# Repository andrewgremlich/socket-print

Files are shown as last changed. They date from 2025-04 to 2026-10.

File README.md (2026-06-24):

# Socket Print (Provel Print)

A utility CAD-like application to apply modifications to a prosthetic limb socket STL file, and output the modifications to a GCode file.

## Getting Started

Requires Node.js 24+ (see `.nvmrc`).

```bash
git clone https://github.com/andrewgremlich/socket-print.git
cd socket-print
npm install
npm run dev
```

Open <http://localhost:4200>.

### Other commands

```bash
npm run build            # Production build (runs tests first)
npm run test             # Run Vitest
npm run check            # TypeScript + Biome
npm run knip             # Find unused files/exports/deps
```

## Deployment

The app is a fully static site deployed to **Cloudflare Workers** via [Workers Static Assets](https://developers.cloudflare.com/workers/static-assets/). No Worker script is required — Cloudflare serves the `dist/` build directly from the edge. Config lives in [wrangler.jsonc](wrangler.jsonc); edge caching/header rules live in [public/\_headers](public/_headers).

```bash
npm run deploy        # Build, then `wrangler deploy`
npm run cf:preview    # Build, then serve the production bundle locally via `wrangler dev`
```

### CI deploys

[.github/workflows/deploy-cloudflare.yml](.github/workflows/deploy-cloudflare.yml) deploys on every push to `main`. Set these repository secrets:

- `CLOUDFLARE_API_TOKEN` — a token with the **Edit Cloudflare Workers** permission
- `CLOUDFLARE_ACCOUNT_ID` — your Cloudflare account ID

The first deploy (locally via `npm run deploy`) creates the Worker and prints its `*.workers.dev` URL; attach a custom domain in the Cloudflare dashboard or via a `routes` entry in `wrangler.jsonc`.

## Offline Support

The app installs a service worker for offline use. See [SERVICE_WORKER.md](SERVICE_WORKER.md).

## Testing GCode Output

To inspect a generated GCode file, use [NCViewer](https://ncviewer.com/).

## Coordinate System Transformation

This application bridges two different coordinate system conventions:

- **Three.js (3D visualization)**: Y-up coordinate system where Y is the vertical axis
- **3D Printing / GCode**: Z-up coordinate system where Z is the vertical axis

### Why This Matters

When generating GCode from Three.js geometries, coordinate transformations are necessary to convert between these systems:

1. **In Three.js**: Objects are positioned with Y representing height
2. **In GCode**: The Z axis represents height (vertical movement)

### Where Transformations Occur

- **[src/3d/generateGCode.ts](src/3d/generateGCode.ts)** — `makeGCodePoint()` and `flipVerticalAxis()` handle the Y↔Z swap when emitting GCode points
- **[src/3d/sliceWorker.ts](src/3d/sliceWorker.ts)** — points are collected in Three.js (Y-up) space and later transformed during GCode generation

Variables like `verticalAxis` and `flipHeight` carry this transformation through the pipeline.

## References

- Pellet extruder flow / RPM: https://dyzedesign.com/2024/05/flow-to-rpm-factor-optimize-your-3d-printing-with-pellet-extruders/
- Clipper polygon-clipping library (under evaluation): https://github.com/junmer/clipper-lib

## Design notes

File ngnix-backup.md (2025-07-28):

Files are build and deployed to `/var/www/socket-print`

`/etc/nginx/sites-enabled/socket-print` is a link to the conf file mentioned here...

`/etc/nginx/sites-available/socket-print`

```conf
server {
    listen 80;
    server_name 209.38.172.166;

    root /var/www/socket-print;

    index index.html;

    location / {
        try_files $uri $uri/ /index.html;
    }

    location ~* \.(?:js|css|png|jpg|jpeg|gif|ico|svg|woff2?|ttf|eot)$ {
        expires 365d;
        add_header Cache-Control "public, max-age=31536000, immutable";
        access_log off;
    }
}
```

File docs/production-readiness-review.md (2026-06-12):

# Production Readiness Review

**Date:** 2026-06-12
**Version reviewed:** 1.22.8 (branch `main`, commit `b33a8a9`)
**Scope:** Full review of offline/PWA capability, slicing/G-code pipeline, error handling, security, and build/test health.

## Resolution Notes (2026-06-12, commit `1fca44b`)

| # | Status | Notes |
|---|---|---|
| 1 | Fixed | Added `<link rel="manifest">` to `index.html` and `help.html` |
| 2 | Won't fix | Chrome prompts for permission on HTTP local-network requests; no change needed |
| 3 | Fixed | `.map` files filtered from precache in `vite-sw-plugin.ts`; extra STLs removed from `vite.config.ts` (only `test_stl_file.stl` kept) |
| 4 | Won't fix | `skipWaiting` kept intentionally for less user interruption |
| 5 | Fixed | Entire DONE branch in `src/renderer.ts` wrapped in try/finally; progress bar and worker always reset on error |
| 6 | Fixed | Empty slice result now throws a user-visible error before G-code generation |
| 7 | Fixed | `store.ts` top-level `initData()` caught with alert instead of silently killing the page; `PrintObject.#showError` now calls `alert()` |
| 8 | Fixed | SW fetch handler now skips non-same-origin requests (`url.origin !== self.location.origin`) |
| 9 | Deferred | Firmware flow intentionally unfinished; comes later |

---

## Verdict

Not production-ready yet. The code quality, testing, and CI are in good shape (build, type checks, and all 305 tests pass cleanly), but there are genuine production blockers — mostly around the PWA/offline story and the HTTPS-vs-printer architecture: the PWA is currently not installable, the service worker ships ~5 MB of sourcemaps to every client, the update flow can break a running session, and there is an unresolved architectural conflict between HTTPS (required for offline) and HTTP printer communication.

## Critical

### 1. The PWA is not installable — no `<link rel="manifest">` anywhere

`public/manifest.webmanifest` exists and is even precached by the service worker, but none of the three HTML files reference it. Browsers will never see it, so there's no install prompt, no standalone mode, no home-screen icon. Add `<link rel="manifest" href="/manifest.webmanifest">` to `index.html` (and ideally `help.html`).

Related: `index.html:11-12` references `/apple-touch-icon.png` and `/mask-icon.svg`, neither of which exists in `public/` — both 404.

### 2. Printer communication will likely be blocked when the app is served over HTTPS

Offline/PWA support requires HTTPS, but `src/3d/printerApi.ts` fetches `http://<printer-ip>/rr_*`. An `http:` fetch from an `https:` page is active mixed content and is blocked by Chrome, Firefox, and Safari before the request even leaves the page — the "skip printer IPs" logic in `public/sw-template.js:85-101` never gets a chance to matter. Chrome's Private Network Access rules add a second layer of blocking for public→local requests.

This means the deployed (Vercel/HTTPS) app can render and slice but **cannot send to the printer** — the core function. Options:

- Serve the app from the printer's LAN over plain HTTP (sacrificing the service worker, which only registers on HTTPS/localhost)
- Put a TLS proxy in front of the Duet
- Package the app (Electron/Tauri) where mixed-content rules don't apply

Verify this on real hardware before anything else, because it determines the whole deployment story.

### 3. The service worker precaches all sourcemaps — ~5.3 MB wasted per client, per update

`vite-sw-plugin.ts:18` takes every bundle key, including `.map` files. The generated `dist/sw.js` confirms it: `main.js.map` (1.7 MB), `three.js.map` (3 MB), `sliceWorker.js.map`, etc. Combined with 5.4 MB of sample STLs and the cache version containing `Date.now()` (so **every** build invalidates everything), each release re-downloads ~20 MB.

Filter `.map` files out of the asset list, and consider whether all four demo STLs belong in the precache.

### 4. The update flow can break an actively running session

`public/sw-template.js` uses `skipWaiting()` + `clients.claim()` + immediate deletion of old caches on activate. When an update lands mid-session, the old page is still running, but its hashed lazy assets (the `Settings` chunk, the slice worker module, fonts) are deleted from cache. If the user is offline or the server has dropped the old hashes, lazy loads fail until reload. The update banner mitigates this, but it auto-dismisses after 30 seconds (`src/web-components/UpdateNotification.ts:40-45`).

Either drop `skipWaiting` so the new SW activates on next navigation, or reload automatically on `controllerchange`, and make the banner persistent.

## High

### 5. Slicing errors leave the UI stuck

In `src/renderer.ts:204-253`, only G-code *delivery* is wrapped in try/catch. If `blendHardEdges`, `calculateFeedratePerLevel`, or `generateGCode` throws inside the async `onmessage` handler, the progress bar stays up forever, the worker is never terminated, and the user gets nothing — the try/catch around `slicingAction()` at the button level can't catch errors from that callback. Wrap the whole DONE branch and `reset()`/`terminate()` in a `finally`.

### 6. An empty slice result still produces and sends G-code

`vaseMode` in `src/3d/sliceWorker.ts:107-109` bails out of a layer (or returns `[]` entirely) when ray casts miss. The main thread doesn't check for an empty/short result — it will happily generate a header + transition layer + end sequence and upload it to the printer. For a device that extrudes hot plastic onto a prosthetic cup, guard `data.length === 0` (and arguably a minimum layer count) with a user-facing error.

### 7. No user-visible error surface for initialization/database failures

`src/db/store.ts:70` does a top-level `await initData()`; if IndexedDB is unavailable (Firefox private browsing, storage pressure, corrupted DB), the module rejection kills the entire `renderer.ts` import chain and the user gets a dead page with the loading spinner state. Similarly, `PrintObject.#showError` (`src/classes/PrintObject.ts:147-149`) only writes to `console.error`, so "Failed to save file to database" and friends are invisible. The log interceptor is a nice foundation — pair it with a simple visible error banner.

### 8. Cross-origin responses are cached forever by the cache-first strategy

The service worker fetch handler caches *any* successful GET — including `https://api.github.com/.../releases/latest` used by the firmware-update check. Cache-first means the "latest firmware" answer is frozen at whatever was first cached until the next app release rotates the cache. Limit SW caching to `location.origin`, or use network-first for non-origin requests.

### 9. The firmware flow looks unfinished

`public/firmware/release.json` contains placeholder data (`"test"`, version `0.0.0`, empty URL). If the Settings firmware-update path reads this in production, it should be populated or the feature gated before release. Also note `getLatestFirmwareRelease` is unauthenticated GitHub API (60 req/hr/IP rate limit) and online-only.

## Medium

- **Offline gaps in precache**: the Inter fonts (`/Inter/*.ttf`, referenced from `src/global-style.css`) and `/styles/update-notification.css` (loaded inside the UpdateNotification shadow DOM) aren't in the `staticAssets` list. They get runtime-cached only after first use, and a cache-version bump evicts them — a user who updates online and then goes offline loses fonts and banner styling.
- **Duplicate element**: `index.html` has `<app-info>` twice (lines 151 and 155). If its shadow-DOM-external behavior involves IDs or singleton assumptions, this is a latent bug; at minimum it's dead weight.
- **Printer reconnect gives up permanently**: after 10 failed retries (`src/utils/handlePrinterConnection.ts:65-77`), polling stops until the user edits the IP field. Consider resuming on `window` `online` events or a slow background interval, since "printer powered on after the app" is a normal sequence in a clinic.
- **No security headers**: `vercel.json` only sets `installCommand`. Adding `Content-Security-Policy`, `X-Content-Type-Options: nosniff`, and an explicit `Cache-Control: no-cache` on `/sw.js` would harden the deployment cheaply.
- **`navigator.onLine` is unreliable** as the sole signal for the OfflineIndicator (it reports "online" when connected to a router with no internet — exactly the clinic LAN scenario). A periodic fetch probe of a tiny same-origin resource is more truthful.

## Low / nits

- `index.html:8` — `<meta description="...">` is invalid; should be `<meta name="description" content="...">`.
- `manifest.webmanifest` — `short_name: "PP"` is what appears under the installed icon; icons lack `"purpose": "maskable"`; no `id` field.
- `help.html` SW comment says "both HTTPS and localhost" but the code registers only on HTTPS.
- Dead `sync`/`push` listeners in `public/sw-template.js:169-178`.
- `hotkeys("ctrl+shift+r")` re-implements a native browser shortcut — unnecessary and can mask hard-refresh.
- `src/utils/logInterceptor.ts` log array grows unbounded for the session; cap it (e.g., ring buffer of 5k entries).
- `generateGCodeButton` is cast to `HTMLInputElement` but is a `<button>` — harmless but misleading.

## What's already in good shape

- Tests: 305 passing across 23 files, with real coverage of geometry and G-code math
- Clean `tsc` + Biome checks
- Fast, reproducible production build
- Tag-vs-version validation in the release workflow
- BVH-accelerated slicing offloaded to a Web Worker
- Consistent geometry/material disposal
- IndexedDB persistence with a versioned schema and a documented migration
- Genuine accessibility effort (aria attributes, reduced-motion handling, focus management)

## Suggested priority order

1. Fix the manifest link (#1 — five minutes)
2. Strip sourcemaps from the precache (#3 — one line in `vite-sw-plugin.ts`)
3. Resolve the HTTPS/printer question (#2) on real hardware — its answer may change how much the rest of the PWA work matters

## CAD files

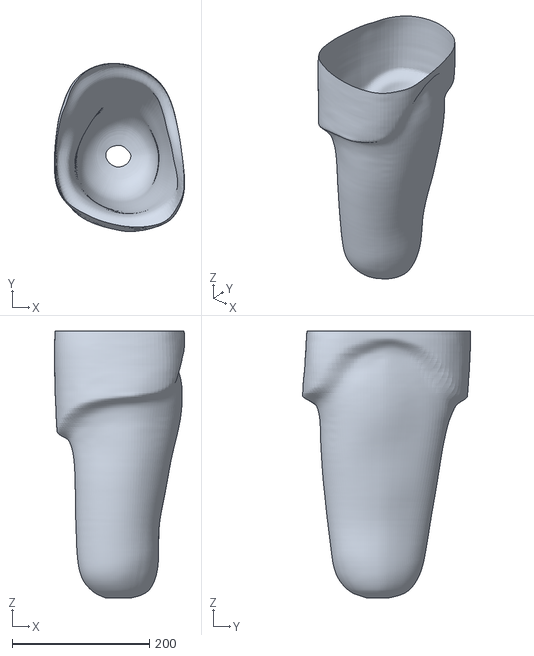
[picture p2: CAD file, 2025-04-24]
public/TF-IschialContainment.stl
189.9 x 245.2 x 389.1

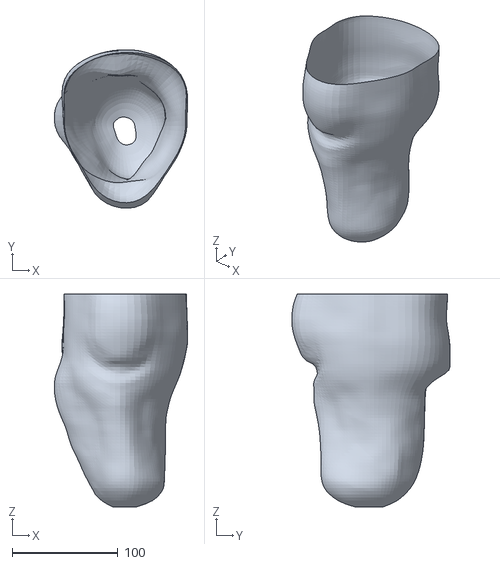
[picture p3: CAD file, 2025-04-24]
public/test_stl_file.stl
126.0 x 149.5 x 201.0

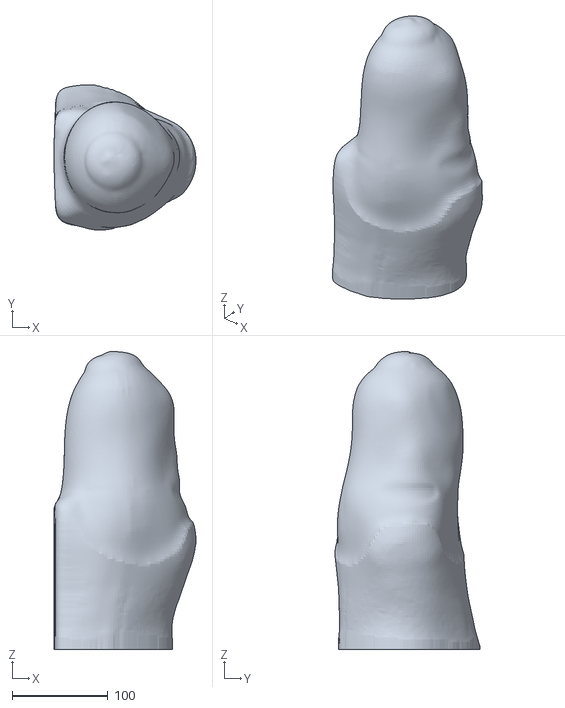
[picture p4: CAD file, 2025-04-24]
public/Crosswalk.stl
148.0 x 151.5 x 310.8

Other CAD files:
public/acme_J_needs-trimming.stl

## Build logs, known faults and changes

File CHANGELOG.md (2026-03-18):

## [1.20.2](https://github.com/andrewgremlich/socket-print/compare/v1.18.5...v1.20.2) (2026-03-18)

## [1.20.1](https://github.com/andrewgremlich/socket-print/compare/v1.19.1...v1.20.1) (2026-03-08)

## [1.20.0](https://github.com/andrewgremlich/socket-print/compare/v1.17.1...v1.20.0) (2026-03-04)

### Bug Fixes

* exclude TransformControls helper meshes from slicing geometry ([393f6a7](https://github.com/andrewgremlich/socket-print/commit/393f6a7321aeef389e59ff8a8db9675709bbcd4f))

## [1.17.1](https://github.com/andrewgremlich/socket-print/compare/v1.17.0...v1.17.1) (2026-01-29)

## [1.17.0](https://github.com/andrewgremlich/socket-print/compare/v1.16.1...v1.17.0) (2026-01-27)

### Bug Fixes

* upgrade dexie from 4.2.1 to 4.3.0 ([#17](https://github.com/andrewgremlich/socket-print/issues/17)) ([31c658d](https://github.com/andrewgremlich/socket-print/commit/31c658def43a1cc310776123de3af92c874988e5))

## [1.16.1](https://github.com/andrewgremlich/socket-print/compare/v1.16.0...v1.16.1) (2026-01-21)

## [1.16.0](https://github.com/andrewgremlich/socket-print/compare/v1.15.7...v1.16.0) (2026-01-20)

## [1.15.7](https://github.com/andrewgremlich/socket-print/compare/v1.15.6...v1.15.7) (2026-01-17)

## [1.15.6](https://github.com/andrewgremlich/socket-print/compare/v1.15.5...v1.15.6) (2026-01-15)

## [1.15.5](https://github.com/andrewgremlich/socket-print/compare/v1.15.4...v1.15.5) (2026-01-14)

## [1.15.4](https://github.com/andrewgremlich/socket-print/compare/v1.15.3...v1.15.4) (2026-01-13)

## [1.15.3](https://github.com/andrewgremlich/socket-print/compare/v1.15.2...v1.15.3) (2026-01-13)

## [1.15.2](https://github.com/andrewgremlich/socket-print/compare/v1.15.1...v1.15.2) (2026-01-13)

## [1.15.1](https://github.com/andrewgremlich/socket-print/compare/v1.14.3...v1.15.1) (2026-01-13)

## [1.14.3](https://github.com/andrewgremlich/socket-print/compare/v1.14.2...v1.14.3) (2026-01-08)

## [1.14.2](https://github.com/andrewgremlich/socket-print/compare/v1.14.1...v1.14.2) (2026-01-07)

## [1.14.1](https://github.com/andrewgremlich/socket-print/compare/v1.14.0...v1.14.1) (2026-01-07)

## [1.14.0](https://github.com/andrewgremlich/socket-print/compare/v1.13.8...v1.14.0) (2026-01-02)

## [1.13.8](https://github.com/andrewgremlich/socket-print/compare/v1.13.7...v1.13.8) (2025-12-30)

## [1.13.7](https://github.com/andrewgremlich/socket-print/compare/v1.13.6...v1.13.7) (2025-12-26)

## [1.13.6](https://github.com/andrewgremlich/socket-print/compare/v1.13.5...v1.13.6) (2025-12-26)

## [1.13.5](https://github.com/andrewgremlich/socket-print/compare/v1.13.4...v1.13.5) (2025-12-24)

## [1.13.4](https://github.com/andrewgremlich/socket-print/compare/v1.13.3...v1.13.4) (2025-12-24)

## [1.13.3](https://github.com/andrewgremlich/socket-print/compare/v1.13.2...v1.13.3) (2025-12-24)

## [1.13.2](https://github.com/andrewgremlich/socket-print/compare/v1.13.1...v1.13.2) (2025-11-04)

## [1.13.1](https://github.com/andrewgremlich/socket-print/compare/v1.13.0...v1.13.1) (2025-11-04)

## [1.13.0](https://github.com/andrewgremlich/socket-print/compare/v1.12.5...v1.13.0) (2025-10-31)

## [1.12.5](https://github.com/andrewgremlich/socket-print/compare/v1.12.4...v1.12.5) (2025-10-27)

## [1.12.4](https://github.com/andrewgremlich/socket-print/compare/v1.12.3...v1.12.4) (2025-10-23)

## [1.12.3](https://github.com/andrewgremlich/socket-print/compare/v1.12.2...v1.12.3) (2025-10-23)

### Bug Fixes

* nozzle temp not setting for machine ([908c6d9](https://github.com/andrewgremlich/socket-print/commit/908c6d91b1a3ad1b6987bafc9848d77e6ec3962f))

## [1.12.2](https://github.com/andrewgremlich/socket-print/compare/v1.12.1...v1.12.2) (2025-10-18)

## [1.12.1](https://github.com/andrewgremlich/socket-print/compare/v1.12.0...v1.12.1) (2025-10-18)

## [1.12.0](https://github.com/andrewgremlich/socket-print/compare/v1.11.5...v1.12.0) (2025-10-18)

## [1.11.5](https://github.com/andrewgremlich/socket-print/compare/v1.11.3...v1.11.5) (2025-10-14)

## [1.11.3](https://github.com/andrewgremlich/socket-print/compare/v1.11.1...v1.11.3) (2025-10-13)

## [1.11.1](https://github.com/andrewgremlich/socket-print/compare/v1.11.0...v1.11.1) (2025-10-09)

## [1.11.0](https://github.com/andrewgremlich/socket-print/compare/v1.10.7...v1.11.0) (2025-10-04)

## 1.10.7 (2025-10-03)

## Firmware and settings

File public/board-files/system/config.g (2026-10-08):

; Configuration file for Duet 3 MB 6XD (firmware version 3.6)
; executed by the firmware on start-up
;
; ------------------------------
; PROVEL PRINTER CONFIG FILE
; VERSION: 0.5
; DATE:2025-Feb-12
;-------------------------------
;

; General preferences
M575 P1 S1 B57600                                 ; enable support for PanelDue
G90                                               ; send absolute coordinates...
M83                                               ; ...but relative extruder moves
M550 P"ProvelPrinter1"                            ; set printer name
M586 C"*"         ;enable CORS

; Network
M552 P192.168.10.14 S1                            ; enable network and set IP address
;M553 P255.255.255.0                               ; set netmask
;M554 P192.168.10.254                               ; set gateway
M586 P0 S1                                        ; enable HTTP
M586 P1 S0                                        ; disable FTP
M586 P2 S0                                        ; disable Telnet

;pre declare speed override variable
if !exists(global.extruderFeed)
  global extruderFeed = 8200                     

; Drives
M569 P0.0 S0                                     ; physical drive 0.0 goes forwards
M569 P0.1 S0                                     ; physical drive 0.1 goes forwards
M569 P0.2 S1                                     ; physical drive 0.2 goes forwards
M569 P0.3 S0                                     ; physical drive 0.3 goes forwards
M569 P0.0 T1:1:1:1                               ;test - step pulse timing of 1uS
M569 P0.1 T1:1:1:1
M584 X0.0 Y0.1 Z0.2 E0.3                         ; set drive mapping
;M92 X14.80 Y22.2 Z210.50 E22.4                   ; set steps per mm  (if E1600 a movement of 1"mm" = 1 screw revolution)
;M92 X14.80 Y22.2 Z210.50 E51.00                  ; set steps per mm old extruder befoe gearing changes
M92 X14.80 Y22.2 Z210.50 E99.00                  ; set steps per mm  update to 51* new gear ratio

M566 X900.00 Y900.00 Z60.00 E1000.00               ; set maximum instantaneous speed changes (mm/min) extuder jer increased to allow for smooth movement with the algorithim expanded files
M203 X6000.00 Y6000.00 Z1800.00 E{global.extruderFeed} I0.001          ; set maximum speeds (mm/min) minimum feedrate
M201 X500.00 Y500.00 Z20.00 E250.00               ; set accelerations (mm/s^2)

; Axis Limits
M208 X-200:185 Y-170:250 Z0:506.6

; Endstops
M574 X1 S1 P"io3.in"                              ; configure switch-type (e.g. microswitch) endstop for low end on X via pin io3.in
M574 Y1 S1 P"io4.in"                              ; configure switch-type (e.g. microswitch) endstop for low end on Y via pin io4.in
M574 Z2 S1 P"io5.in"                              ; configure switch-type (e.g. microswitch) endstop for High end on Z via pin io5.in

; Z-Probe
M558 P0 H5 F120 T6000                             ; disable Z probe but set dive height, probe speed and travel speed
M557 X20:480 Y20:480 S40                          ; define mesh grid

; Heaters and temperature sensors
M308 S0 P"temp0" Y"thermistor" A"BedTemp" T100000 B4138              ; configure sensor 0 as thermistor on pin temp0
M950 H0 C"out2" T0                                                   ; create bed heater output on out7 and map it to sensor 0
M307 H0 R0.632 K0.373:0.000 D3.55 E1.35 S1.00 B0                     ; disable bang-bang mode for the bed heater and set PWM limit
M140 P0 H0                                                           ; map heated bed to heater 0
M143 H0 S120                                                         ; set temperature limit for heater 0 to 120C
M308 S1 P"temp1" Y"pt1000" A"NozzleTemp"                             ; configure sensor 1 as PT1000 on pin temp1
M950 H1 C"out0" T1                                                   ; create nozzle heater output on out0 and map it to sensor 1
;M307 H1 R0.836 K0.060:0.000 D43.70 E1.35 S1.00 B0 V24.1              ; old tuning for old heater barrel
;M307 H1 R1.278 K0.106:0.154 D19.00 E1.35 S1.00 B0 V24.0   
;M307 H1 R0.735 K0.046:0.000 D58.84 E1.35 S1.00 B0 V23.9              ; new barrel heater 10.04.25 
M307 H1 R0.635 K0.050:0.000 D68.50 E1.35 S1.00 B0 V24.2               ;2.19.26
M143 H1 S350                                                         ; set temperature limit for heater 1 to 350C
M570 H1 T30 P30; for development only

M308 S2 P"temp2" Y"thermistor" A"CupTemp" T100000 B4138              ; configure sensor 2 as thermistor on pin temp2
M950 H2 C"out1" T2                                                   ; create nozzle heater output on out1 and map it to sensor 2
;M307 H2 R0.796 K0.247:0.000 D12.13 E1.35 S1.00 B0                      ; disable bang-bang mode for heater  and set PWM limit
;M307 H2 R3.183 K1.538:0.000 D1.02 E1.35 S1.00 B0                    ;old tuning for old cup heater 6.18.25

;M307 H2 R1.095 K0.484:0.000 D5.98 E1.35 S1.00 B0                    ;new cup heater tuning 6.19.25 #1
;M307 H2 R1.199 K0.559:0.000 D6.43 E1.35 S1.00 B0                    ;new cup heater tuning 6.19.25 #2 extra silicon insulation
;M307 H2 R1.527 K0.635:0.000 D5.67 E1.35 S1.00 B0                    ;new cup heater tuning 6.19.25 #3 fiber insulation
;M307 H2 R1.520 K0.660:0.000 D6.01 E1.35 S1.00 B0                    ;new cup heater tuning 7.16.25 #4 sand dollar top
;M307 H2 R1.927 K0.644:0.000 D3.50 E1.35 S1.00 B0                    ;new cup heater tuning 7.23.25 #5 new heater
;M307 H2 R1.948 K0.613:0.000 D3.66 E1.35 S1.00 B0                    ;new cup heater tuning 7.25.25 #6 target 170C 
M307 H2 R1.940 K0.656:0.000 D3.53 E1.35 S1.00 B0                     ;new cup heater tuning 7.31.25 #7 target 160C

M140 P1 H2                                                           ; map cup heater as second heated bed to heater2
M143 H2 S210                                                         ; set temperature limit for heater 2 to 210C
M308 S3 P"temp3" Y"thermistor" A"EnclosureTemp" T100000 B4138        ; configure sensor 3 as thermistor on pin temp3

M950 H3 T3 C"io2.out"                     ; create a dummy heater on io2.out to allow enclosure temperature faults to be raised
M141 P0 H3                                ; configure the dummy heater as a chamber heater
M143 H3 P0 T3 A0 C0 S50                   ; configure a heater fault to be raised if the enclosure temperature goes above 50C, use heater-fault.g to handle it

M302 P0 S180 R180                         ; set temp at which cold extrude is allowed  

; Fans
M950 F0 C"!out3" Q500                              ; create fan 0 on pin out4 and set its frequency
M106 P0 C"Exhaust" S0 H-1                         ; set fan 0 name and value. Thermostatic control is turned off
M950 F1 C"!out4" Q500                              ; create fan 1 on pin out5 and set its frequency
M106 P1 C"PelletFeed" S0 H-1                            ; set fan 1 name and value. Thermostatic control is turned off
M950 F2 C"!out5" Q500                              ; create fan 2 on pin out6 and set its frequency
M106 P2 C"PartCooling" S0 H-1                            ; set fan 2 name and value. Thermostatic control is turned off
M950 F3 C"out6" Q500                              ; create fan 3 on pin out7 and set its frequency
M106 P3 C"Extruderservo" S1 H1 T100                         ; set fan 3 name and value. Thermostatic control is turned off
M950 F4 C"out7" Q500                              ; create fan 3 on pin out7 and set its frequency
M106 P4 C"PelletPump" S0 H-1                          ; set fan 3 name and value. Thermostatic control is turned off

; Tools
M563 P0 D0 H1 F2                                  ; define tool 0
G10 P0 X0 Y0 Z0                                   ; set tool 0 axis offsets
G10 P0 R0 S0                                      ; set initial tool 0 active and standby temperatures to 0C

;Other control and IO

M950 J1 C"io7.in"                                      ; io7.in as a input switch for the door latch
;M308 S10 P"io7.in" Y"linear-analog" A"pellet-feed"
M950 J2 C"io8.in"                                      ; io8.in as a input switch for the Emergency stop
M308 S10 P"io6.in" Y"linear-analog" A"pellet-feed"
M581 T2 P2 S0 R0                                       ; create trigger2 for monitoring the estop switch

; Miscellaneous
;M501                                              ; load saved parameters from non-volatile memory ; commented out 8.14.25 by KF
;M911 S21 R19 P"M913 X0 Y0 G91 M83 G1 Z3 E-5 F1000 ;CHANGE THIS" ; set voltage thresholds and actions to run on power loss
T0                                                ; select first tool
M17 XYZ
M17 E0
;set firmware retraction length to 0.
M207 P0 S0
;segmentation
;M669 T0.1 ; set segmentation lenght to 0.1

;----------------
;--Setup global variables for UI & Printer Management
;----------------
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

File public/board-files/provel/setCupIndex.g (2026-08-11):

set global.xIndex = -198.784
set global.yIndex = -165.991
M208 X-198.784:185 Y-165.991:300

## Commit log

2025-04-24 password leaks... oops
    [Crosswalk.stl, TF-IschialContainment_20151230164058.stl, acme_J_needs-trimming.stl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]
2025-04-24 increasing feedrate speed for cup heater portion
2025-05-16 unzip output into socket-rpitn in home
2025-05-16 adding test stage and refining copy
2025-05-16 double checking printer connection
2025-05-21 BUG FIXES
    The model was being truncated due to the merge of the cylinder and
    model. Fixed!
    The model was being mirrored. Fixed!
2025-05-23 working on socket and ring intersection calc
2025-05-23 optional ring prop
2025-05-30 adding test cylinder
2025-06-10 swap material form to use native dialog
2025-06-27 Testing review changes
    Variable feedrate perlayer
    Adding Info dialog
    Clear model removes all
    print status update loop fix
2025-06-28 printer connection enhancement
2025-07-10 CCW print and Comment fix
2025-08-05 basic changes
    [cylinder.stl]
2025-08-05 modified extrusion to be custom
2025-08-14 V1.5.0 (#9)
    * almost all v1.5.0 changes. just need saving translate
    * persist translate and rotate
    * some UI changes
    * quick changes
    [CylinderTest77x50.stl, CylinderTest77x60.stl]
2025-08-18 gcode adjustment cup heater removal
2025-08-18 test cylinder flush to zero
    [test_cylinder.stl]
2025-08-18 cylinder vs socket positioning
2025-08-18 nozzle size in for magic 5
2025-08-18 proper cylinder offset display
2025-08-22 connecting cup transition layer to rest of Gcode (#10)
    * cup transition layer good. need E and placement in flow
    * gcode transition layer is forming
    * orientation is good now
    * connecting cup transition layer to rest of Gcode
    * copilot review changes
    * feature bump
2025-08-26 different cup layer extrusion equation
2025-08-28 camera adjustment
2025-08-28 slight camera position adjustment
2025-08-28 nozzle to cup layer extrusion adjustment
2025-09-02 Settings modal (#11)
    * everything gtg for settings modal. a few more things.
    1. Change setting on form change
    2. keyboard shortcut instead of menu option
    * version bump and extrusion adjustment
    * fixing path error
    * MVP, need bug fixes
    * bug prevention
    * Update src/web-components/Settings/index.ts
    * Update src/web-components/Settings/index.ts
    * Update src/web-components/Dialog/index.ts
    * data from indexeddb instead of magic nums
    ---------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
2025-09-02 active material profile name view
2025-09-03 material profile bug fix
2025-09-03 edit material profile set
2025-09-11 Test cylinder (#12)
    * test cylinder implemented
    * renaming things
    * version bump
    * clipping note
    * work for an offset lib
    * final touches
    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
2025-09-18 Offset method (#13)
    * offset method saved
    * offset refinement
    * checkpoint
    * good performance point. wrap up
    * Y position fix (regression)
    * nozzle size offset and upgrades
    * scaling model for shrink
    * scaling properly implemented
    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
2025-09-20 apply offsets to test cylinder
2025-09-23 added test cylinder customization
2025-09-23 test cylinder diameter to 68
2025-10-07 centralizing current getExtrusion calculation
2025-10-09 centralize extrusion calc
2025-10-14 change cupTemp and test cylinder diameter default values
2025-10-18 implementing control extrusion equation
2025-10-18 workings for saving test cylinder
2025-10-23 fix: nozzle temp not setting for machine
2025-10-31 overhaul print object for reusability
2025-12-24 allow for material profile cup temp at 220
2025-12-24 update test cylinder diamter to test cylinder inner diameter
2025-12-26 adding camera min and max distance
2026-01-02 Collision detection with tube and print object
2026-01-07 updating SW
    [TF-IschialContainment.stl]
2026-01-08 sw.js do not intercept printer traffic
2026-01-13 Uat fixes (#16)
    * active sw only on prod
    * updating tube for better reactivity
    * minor fix of db singleton; live queries
    * socket cup upgrade and wall thickness added
    * storing to work later
    * claude review file
    * just get this through
    * 1.15.0
2026-01-13 wireframe in gen offset
2026-01-13 should be able to print socket
2026-01-13 Fix triangular jumps at top of socket prints
    Improved slicing logic to prevent incomplete layers from causing toolpath jumps:
    - Added 95% minimum point threshold per layer
    - Implemented gap detection for consecutive missing intersections (>3)
    - Stop slicing when large angular gaps are detected
    Also documented Y-up (Three.js) to Z-up (GCode) coordinate system transformation in README.
2026-01-13 Fix test cylinder geometry updates and improve memory management
    - Update offset geometry in-place instead of creating new mesh
    - Add onChange callback to TestCylinder for geometry change notifications
    - Track and properly dispose TestCylinder instances in PrintObject
    - Fix camera to only set initial position once on model load
2026-01-13 nozzle size just 1
2026-01-14 Fix shrink scale export and correct nozzle offset factor
    - Bake shrink scale into geometry vertices instead of mesh transform,
    ensuring the compensation is included in exported STL files
    - Change NOZZLE_SIZE_OFFSET_FACTOR from 1 to 2 for correct inner
    diameter compensation (half nozzle width)
    - Add debug logging to track geometry dimensions through offset,
    scale, and export steps
    - Remove stray console.log from TestCylinder
2026-01-15 socket file loading fix
2026-01-17 Replace custom icon component with Lucide icons library
    Migrated from custom icon-element web component to Lucide icons for
    simpler icon management. Removed test STL/GCODE files and old service
    worker that were no longer needed.
    [CylinderTest77x60.stl, cylinder.stl, test_cylinder.stl]
2026-01-17 Fix BVH intersection for complex STL files
    Move BVH creation to after geometry.translate() so the bounds tree
    matches the actual vertex positions. Previously the BVH was created
    before the translate, causing intersection tests to fail on larger
    STL files like Crosswalk.stl.
2026-01-17 Fix rotation save/restore to use actual mesh Euler angles
    Save mesh.rotation values directly instead of accumulating rotation
    amounts manually. This fixes inconsistent rotation restoration between
    different STL files.
2026-01-20 Add Inter font and CSS design system with light/dark theme support
    - Add Inter variable font files
    - Create comprehensive CSS custom properties for colors, spacing, typography
    - Add light theme (default) and dark theme via prefers-color-scheme
    - Update app styles to use design tokens throughout
    - Simplify help page structure
    - Add icons to File and Print buttons
2026-01-20 accurate socket cup
2026-01-20 replacing socket cup math with mathjs lib
2026-01-20 I guess printobject actually works
2026-01-27 New Cup to Socket Merge (#18)
    * new cuptosocket transition
    * slight fixes
    * test cleanup
    * refactor: extract utility modules from PrintObject
    Extract reusable logic into separate utility modules:
    - stlLoader.ts: STL file reading and database export
    - meshTransforms.ts: rotation/translation helpers with DB sync
    - printObjectEvents.ts: event listener setup/teardown
    * splitting up printobject
    ---------
2026-01-29 material profile defaults
2026-02-04 new fine tune z rotation button
2026-02-04 fix: exclude TransformControls helper meshes from slicing geometry
    TransformControls adds helper meshes (X, Y, Z, XYZE, etc.) to the scene
    with large scale factors (~92x). When collectAllGeometries applied
    matrixWorld to these meshes, it produced maxHeight values of ~39000
    instead of ~200, breaking the slicing progress calculation.
    The fix walks up each object's parent chain and skips any mesh that is a
    descendant of the TransformControls helper.
    Also removes unused Rotate3D icon which was causing console warnings.
2026-02-14 Refactor geometry collection to use explicit userData flags for slicing
    Instead of excluding meshes by type (TransformControls, TextGeometry,
    RingGeometry), meshes are now opted-in via userData flags (isSocket,
    isSocketCup, isTransition). Also fixes transform controls detachment
    on mesh removal and resets rotation button state when meshes are cleared.
2026-02-18 Fix test cylinder G-code by marking mesh with isPrintObject userData flag
    Test cylinder mesh was excluded from geometry collection for slicing
    because it lacked the userData flag. Renamed isSocket to isPrintObject
    to accurately describe both imported STL sockets and test cylinders.
2026-02-18 Increase test cylinder max height from 50 to 100
2026-02-24 Layout refresh (#20)
    * update layout
    * nav bar is web component. application grid instead of flex
    * Rename rotation labels from anatomical to axis-based (coronal→X, sagittal→Y, transverse→Z)
    Renames all rotation references across HTML, TypeScript source, types, DB actions,
    event handlers, and tests to use X/Y/Z axis naming instead of coronal/sagittal/transverse.
    * Rename translation labels from directional to axis-based (horizontal→X, depth→Y, vertical→Z)
    Renames all translation references across HTML IDs, TypeScript exports, event handlers,
    callbacks, methods, and tests to use xTranslate/yTranslate/zTranslate naming.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
2026-03-01 Update help docs, bump dependencies, and improve G-code generation
    - Add introduction section to help page explaining app workflow
    - Reorder and update Translate/Rotate help sections
    - Bump lint-staged to 16.3.1 and three to 0.183.2
    - Move enclosure blower thermostatic control after temperature wait
    - Add smooth E value interpolation on first print layer for better
    transition from cup to socket
    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
2026-03-04 Web component input (#21)
    * new input web component
    * web component progress bar
    * web component clean up
    * claude update
    * Remove Tauri desktop app in favor of web-only deployment
    The app is now a pure web application. Remove all Tauri backend code,
    dependencies, build scripts, icons, and Tauri-specific code paths in
    the frontend (updater, dialog/fs file saving, isTauri global).
    * Add non-intrusive UpdateNotification web component for SW updates
    Replace the blocking window.confirm() dialog with a subtle bottom
    banner that shows reload/dismiss buttons when a new service worker
    version is detected. Auto-hides after 3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
2026-03-08 refreshed transition layer ramp down and clamp
2026-03-18 fix cup-to-socket transition not clearing on position change
    Transition meshes were orphaned in the scene because checkCollision()
    had early-return paths that never disposed the existing transition.
    Also fixed a race condition where overlapping async computations could
    leave stale meshes in the scene by adding a compute ID guard and a
    scene-level cleanup of all isTransition objects.
2026-03-18 log download button
2026-03-22 Cleaning up PrintObject and making sense of it
2026-03-22 updated mock printer
2026-03-22 renaming to printerApi file
2026-03-27 update notification to distinguish major vs minor/patch version changes
    Service worker now posts the app version to clients on activation.
    UpdateNotification compares the new major version against the current
    version and shows "major update available" or "new version available"
    accordingly. Also skips SW registration during dev and extracts
    notification styles to external CSS.
2026-04-10 Updater in settings (#22)
    * html structure in settings modal
    * add firmware update flow to Settings with board info detection
    Implements full OTA firmware update workflow: fetch board info via
    rr_model, compare against latest GitHub release, and update firmware
    via upload/flash/poll cycle. Mock printer updated with rr_model and
    rr_reply endpoints for testing.
    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
2026-04-29 use seconds per layer switch off defaults to 34 minute duration. circular resolution increase
2026-05-11 update collision UI when test cylinder diameter changes via live query
    The liveQuery-triggered recompute in CupToSocketTransition bypassed
    checkCollision, leaving the imperfect fit warning stale. Added a
    recompute callback that propagates back through CollisionDetector to
    PrintObject's checkCollisionAndUpdateUI.
2026-05-13 Fix CupToSocketTransition rendering: solid blue on hit, red wireframe on miss
    Previously the mesh was always added to the scene before the hit/miss check,
    causing a hybrid red+blue appearance when transitioning states. The miss case
    now shows a red wireframe band so misalignment is still visible, while the hit
    case shows a solid blue mesh with wireframe explicitly disabled.
2026-05-13 Add per-axis rotation degree displays next to rotate buttons
    Shows current 0-360° value for X, Y, Z next to each button, updating on
    both 90° button clicks and drag-rotate. Resets to 0° when model is cleared.
    Y/Z axes are swapped to match the 3D printing axis remapping.
2026-05-14 Socketcup transition more accurate feedback
2026-05-20 Add optional double-prime checkbox for clearing purge blockages
    Adds a "Double Prime" checkbox above the File/Print buttons. When
    checked, the start sequence emits two prime.g calls separated by a
    1-second dwell so the user can clearly observe the double prime
    after a long purge. Defaults to off and is session-scoped (not
    persisted to IndexedDB).
2026-05-20 Improve overlay label readability against light models
    Replaces the panel-wide translucent background on the translate/
    rotate controls with per-element pill backgrounds on the spans,
    outputs, and app-input labels. The previous solid panel washed out
    the model behind it; the per-label pills let the 3D view stay
    visible while keeping text legible against a white socket.
2026-05-20 Fix slicer merge failing when transition mesh has a color attribute
    CupToSocketTransition adds a per-vertex color attribute that the
    print object and socket cup don't have, which made
    BufferGeometryUtils.mergeGeometries return null and crashed
    slicingAction with a null property access. Strip every attribute
    except position before merging (the slicer only consumes positions)
    and guard the call site so future merge failures surface clearly
    instead of crashing.
2026-05-20 jacket mode print
2026-06-08 revert flat rate print across all layers. just seconds per layer
2026-06-10 Tighten nozzle temp wait to +/-2C and shift second cup layer 1mm outward radially (#23)
2026-06-12 production readiness fixes: PWA manifest, SW caching, error handling
    - Add <link rel="manifest"> to index.html and help.html so the PWA is installable
    - Filter .map files from service worker precache; drop extra STLs (keep test_stl_file.stl only)
    - Restrict SW fetch interception to same-origin requests only
    - Wrap slicing DONE branch in try/finally so progress bar and worker always reset
    - Guard against empty slice result with a user-visible error
    - Catch top-level initData() failure in store.ts and alert rather than killing the page
    - Make PrintObject.#showError call alert() so DB/file errors are visible to users
2026-06-12 add pan bounds clamping to prevent scene objects from being panned out of view; bump version to 1.22.10
2026-07-22 Extract Dialog/Info/MaterialProfileForm/Settings markup into .css/.html files
    Move Dialog's shared style and each subclass's inline template into
    per-component .css/.html files loaded via ?inline/?raw imports, backed
    by a shared adopted CSSStyleSheet per component. Dialog.attachHTML
    switches from a tagged template to a plain (html, extraStyles?)
    signature since subclasses no longer need template-literal
    interpolation for static markup; Info substitutes its two genuinely
    dynamic values (version, year) via simple string replace.
    Also fixes text-underline-thickness -> text-decoration-thickness in
    Dialog's link style, a pre-existing typo (not a real CSS property)
    that was invisible to Biome whi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
2026-07-22 Extract MenuBar markup into .css/.html files
    Move MenuBar's static template/styles getters into MenuBar.css and
    MenuBar.html loaded via ?inline/?raw, and inline the settings gear SVG
    directly into the HTML now that it no longer needs to be interpolated
    from a JS string constant.
2026-08-11 macro files for provel print
    [access.g, bed.g, cancel.g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]
2026-08-28 test extrusion file
2026-10-08 configurable fan speed through out the print
2026-10-08 use buttons instead of input buttons
2026-10-08 feat: make cup transition speed and heater settings configurable
    Add saved settings for transition speed, heater hold time, and temperature tolerance. Default to 2000 mm/min, 0 seconds, and 0°C tolerance.
    Apply settings to generated G-code and add regression tests for form persistence and heater sequencing.
2026-10-08 fix: halve priming screw speed and bump system board-files version
    Reduce primeFeed from 2350 to 1175 while keeping primeTime unchanged.
    Bump system board-files version to 1.0.1 so Settings detects the upgrade.
    Update priming notes to reflect the speed change and restart requirement.
    [config.g]
